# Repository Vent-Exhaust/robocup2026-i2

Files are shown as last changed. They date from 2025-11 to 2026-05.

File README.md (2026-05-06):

# robocup2026
# Vent Exhaust - RoboCup Singapore Soccer Infrared Junior 

<!-- <img src="https://github.com/2-chairs/robocup2025/blob/main/zLogo/v3/logo%20render%20v3.png" alt="" width="100"/> -->

*Repository for the official electronic, mechanical, and software files of Vent Exhaust (VE) 1, formerly known as 2 Chairs.*

<p align="center">
  <a href="media/photos/_DSC8658.jpg">
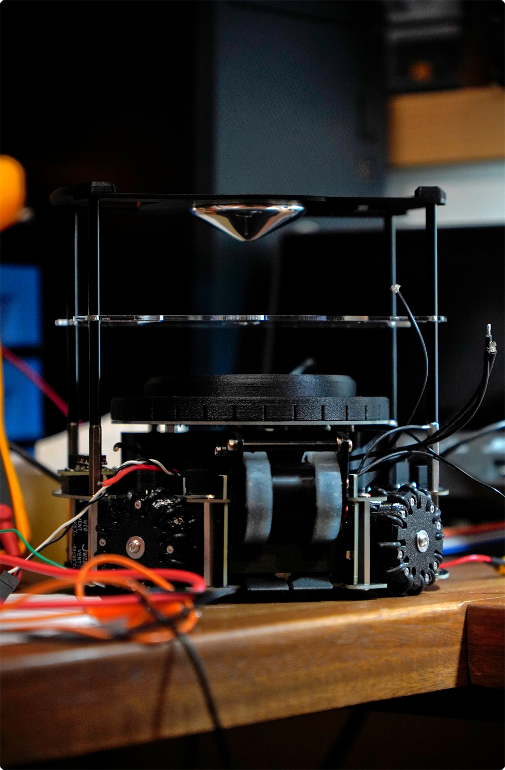
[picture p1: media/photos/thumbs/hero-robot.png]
Vent Exhaust robot
    
  </a>
</p>

## About

This repository is for **Vent Exhaust**, a Singapore RoboCup Infrared Soccer Junior team, and includes relevant design files and resources.

## Repository Structure

- **elec/** - PCB designs, schematics, and component footprints.
- **mech/** - 3D-printable files in **.3MF** and **.STL** formats; includes rendered images of the robot and its mirrored counterpart for reference and other files related to mechanical design.
- **code/** - PlatformIO firmware for the 3-layer robot architecture (Layer 1-3 Teensies / ESP32).
- **cam/** - MicroPython camera firmware (`cam.py`) running on an OpenMV H7 Plus, detecting goals and ball over serial.
- **branding/** - Official team branding and design assets.
- **media/** - Robot photos, gallery thumbnails, screenshots, and reference images used by the README and project documentation.

## Mechanical CAD

- [View the Fusion 360 model](https://a360.co/4tRNy74)

## Robot Gallery

<p align="center">
  <a href="media/photos/bot-with-trophy.jpeg">
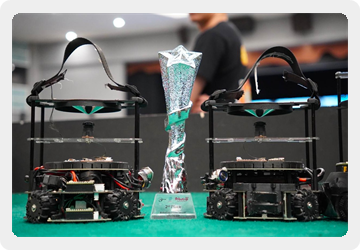
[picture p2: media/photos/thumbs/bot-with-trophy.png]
Robot with trophy
    
  </a>
  <a href="media/photos/_DSC9165.jpg">
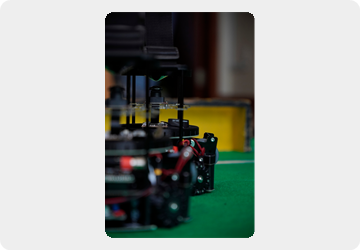
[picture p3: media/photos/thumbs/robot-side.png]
Robot side view
    
  </a>
  <a href="media/photos/_DSC9409.jpg">
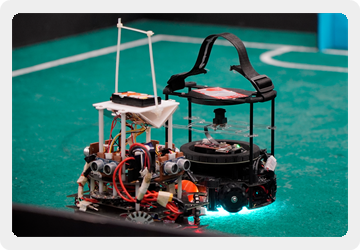
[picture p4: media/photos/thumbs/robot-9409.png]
Robot gallery photo
    
  </a>
  <a href="media/photos/_DSC9172.jpg">
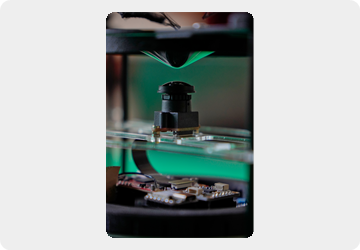
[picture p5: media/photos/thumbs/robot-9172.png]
Robot gallery photo
    
  </a>
  <br>
  <a href="media/photos/_DSC9811.jpg">
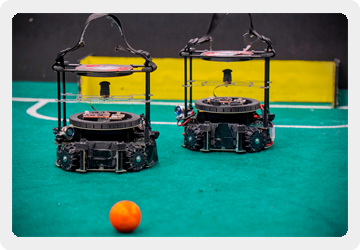
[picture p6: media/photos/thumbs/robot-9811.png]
Robot gallery photo
    
  </a>
  <a href="media/photos/_DSC9160.jpg">
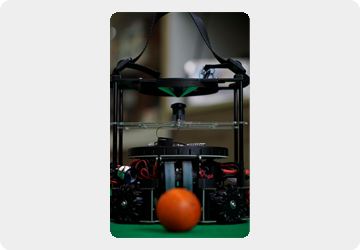
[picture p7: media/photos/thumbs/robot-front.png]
Robot front view
    
  </a>
  <a href="media/photos/_DSC9834.jpg">
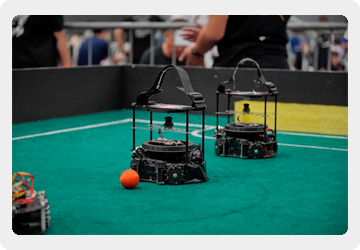
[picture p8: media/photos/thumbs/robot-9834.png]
Robot gallery photo
    
  </a>
</p>

## Robot Architecture

Three processors communicate over UART using a custom SerialComm packet protocol:

| Layer | Hardware | Role |
|---|---|---|
| Layer 1 | Teensy 4.0 | 32-LDR light ring - white line detection |
| Layer 2 | Teensy 4.0 | Main brain - strategy, X-drive motors, IMU heading hold, localisation, scoring |
| Layer 3 | Seeed XIAO ESP32-C3 | 28-IR sensor ring - ball detection + 4 DIP switches |
| Camera | OpenMV H7 Plus (MicroPython) | Dual-goal + ball vision -> serial CSV to Layer 2 |

## Branch Archive

`main` is the active branch. Previous development branches are preserved as
Git tags under `archive/`, such as `archive/i4-v3` and `archive/striker`.

## License & Copyright

Copyright 2026 Vent Exhaust. All rights reserved, except where otherwise stated.

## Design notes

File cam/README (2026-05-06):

cam/
└── cam.py   — MicroPython camera firmware (runs on OpenMV H7 Plus)
                Detects blue goal, yellow goal, and orange ball via colour blobs.
                Outputs a CSV line over UART every frame:

                  BX,<x>,<y>,<dist>,<angle>,<lb_dist>,<lb_angle>,
                  BY,<x>,<y>,<dist>,<angle>,<lb_dist>,<lb_angle>,
                  BALL,<x>,<y>,<dist>,<angle>

                Layer 2 reads this on Serial3 via cam_comm.

Key tuning constants (top of cam.py):
  window_x / window_y     — capture resolution (default 480×480)
  OPTICAL_OFFSET_X/Y      — lens centre correction
  BALL_ROI_SIZE           — square ROI for ball detection
  DEBUG_* flags           — enable/disable drawing overlays and serial debug prints

Coordinate convention:
  x/y — pixel coordinates, origin top-left
  dist — approximate distance derived from blob area (arbitrary units)
  angle — angle to blob centre relative to image centre, degrees
  lb_* — largest-blob variant used for scoring aim

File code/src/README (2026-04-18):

src/
├── layer1/   — Teensy 4.0 — light ring sensing + line detection
│               Reads 32 LDR sensors via MUX, runs findLine(), transmits
│               results (lineDetected, angle, size) to layer2 over Serial1→Serial4.
│               Libraries: light_ring, angle_utils, serial_comm
│
├── layer2/   — Teensy 4.0 — strategy + locomotion
│               Main brain: state machine (ORBIT, IR CHASE, SCORING, RTC, IDLE,
│               LINE DETECTED), X-drive motor control, BNO085 IMU heading-hold PID,
│               camera-based localisation (dual-goal triangulation), dribbler/kicker.
│               Receives: L1 via Serial4, L3 via Serial5, camera via Serial3.
│               Libraries: movement, scoring, cam_comm, layer1_comm, layer3_comm,
│                          serial_comm, angle_utils
│
└── layer3/   — Seeed XIAO ESP32-C3 — IR ball detection + DIP switches
                Polls 28-IR sensor ring, clusters readings to find ball angle,
                reads 4 DIP switches (goal colour, role, strat0, strat1).
                Sends ball angle + switch states to layer2 over Serial1→Serial5.
                Libraries: serial_comm

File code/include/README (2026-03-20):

include/
└── config.h   — project-wide tuning constants, shared across all environments

config.h is the first file to edit on competition day. Sections:

  Light Ring
    LDR_THRESHOLDS[32]        per-sensor white/green thresholds (run calibration to generate)
    LDR_SAMPLES               ADC samples averaged per sensor read
    MUX_SETTLE_US             µs to wait after mux channel switch before reading
    CALIBRATION_READS_PER_SAMPLE

  Main Loop
    LOOP_DELAY_MS             layer1 polling period

  Layer 2 — Motor Trim
    FR_TRIM, BR_TRIM,         per-motor speed multipliers (0.0–1.0)
    BL_TRIM, FL_TRIM          slowest motor stays at 1.0; reduce faster motors

  Layer 2 — IMU Correction
    YAW_KP/KI/KD/I_MAX       heading-hold PID gains
    YAW_CORRECTION_MAX        max omega correction added by yaw PID (0–1 scale)
    ACCEL_KP                  drift correction proportional gain
    ACCEL_CORRECTION_MAX      max vx/vy correction from accel

No other files need to be touched for day-of tuning.

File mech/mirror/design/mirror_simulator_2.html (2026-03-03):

# 🔬 Catadioptric Mirror Simulator

Design and simulate mirrors for OpenMV H7 Plus camera (OV5640 sensor, 2.8mm lens)

### Camera Parameters

Sensor Height (cm): 9.51

Focal Length (mm): 2.8

### Mirror Parameters

Mirror Top Height (cm): 17.03

Viewing Range (cm): 150

Cone Radius Param (cm): 4.7 Controls mirror width

Resolution: 200

🔄 Regenerate Mirror 💾 Download Profile Data 📦 Export for Fusion 360

### 📊 Mirror Stats

Generating...

### ℹ️ Instructions

1. Adjust parameters above
2. Watch the mirror shape update
3. Download profile for Fusion 360
4. Pink rays: ground to mirror
5. Green rays: mirror to lens

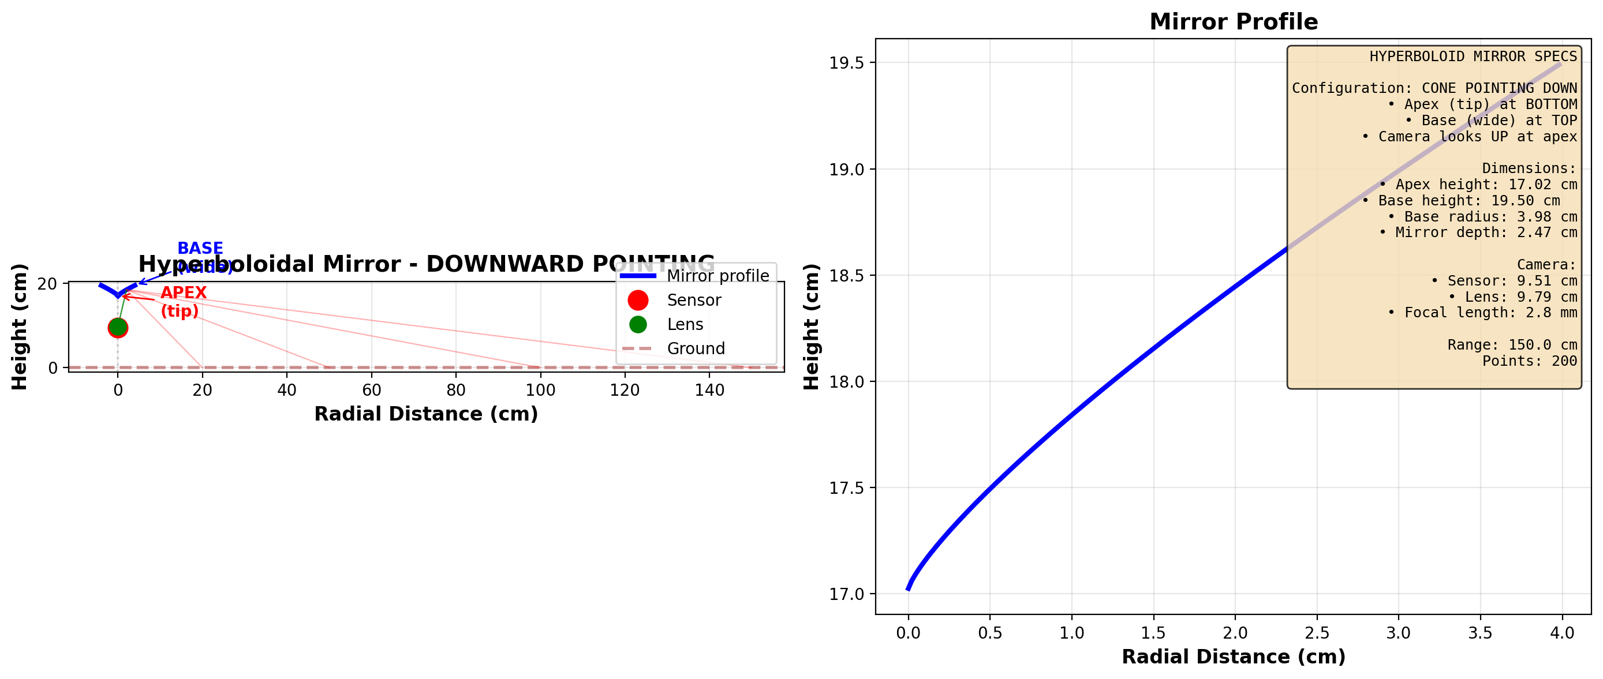
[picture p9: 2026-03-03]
mech/mirror/design/hyperboloid_mirror.png

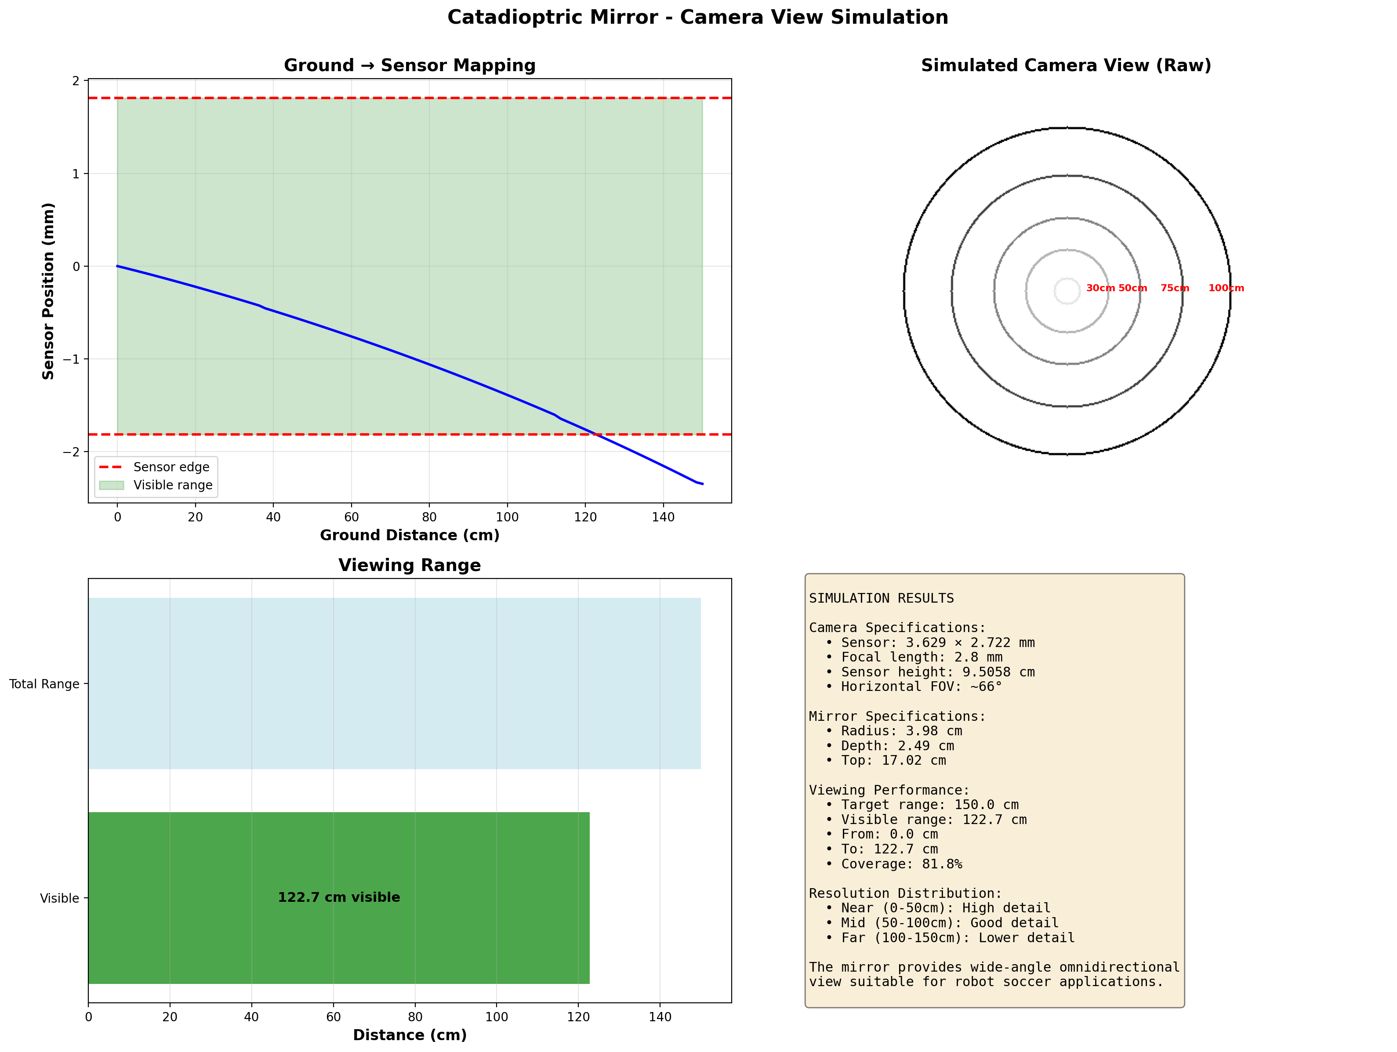
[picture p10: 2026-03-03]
mech/mirror/design/camera_view_simulation.png

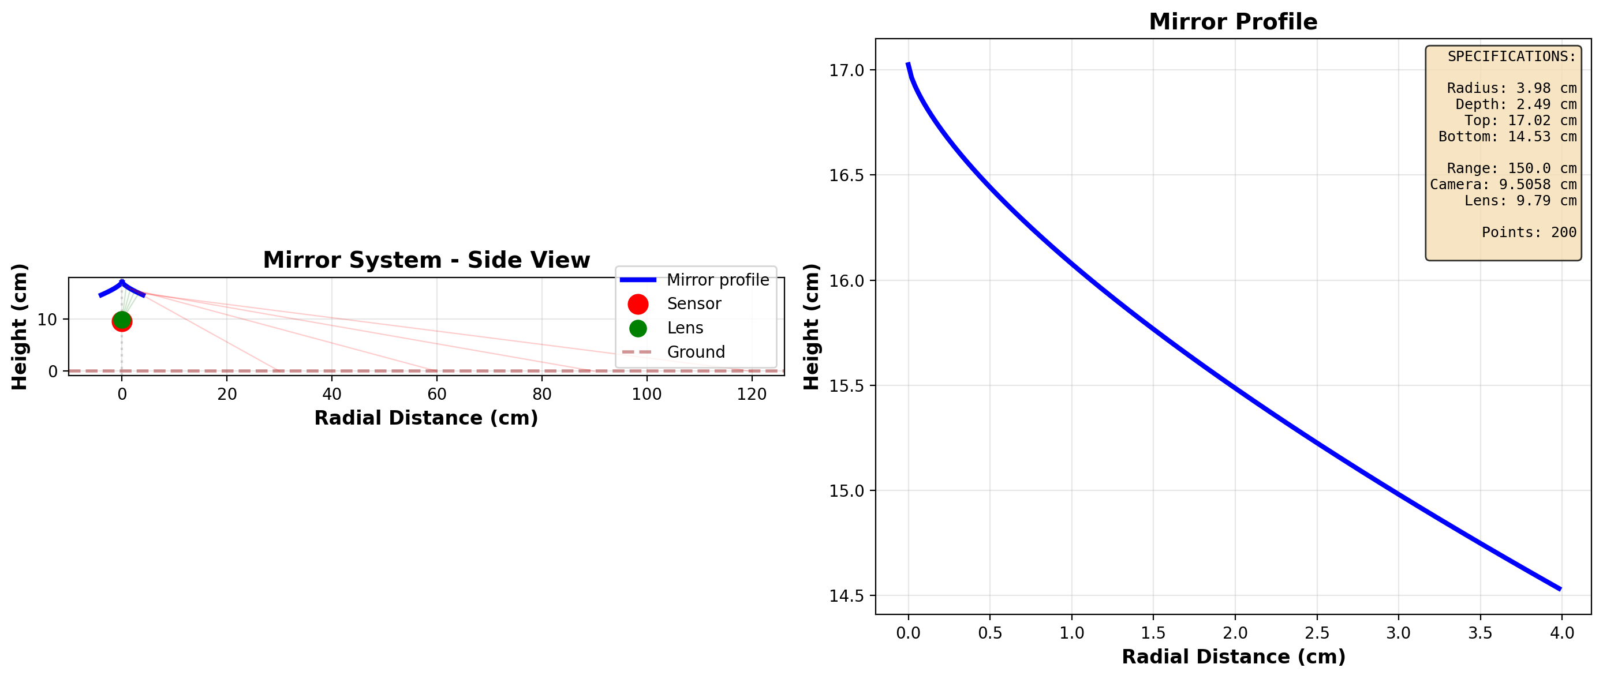
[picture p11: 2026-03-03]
mech/mirror/design/mirror_final.png

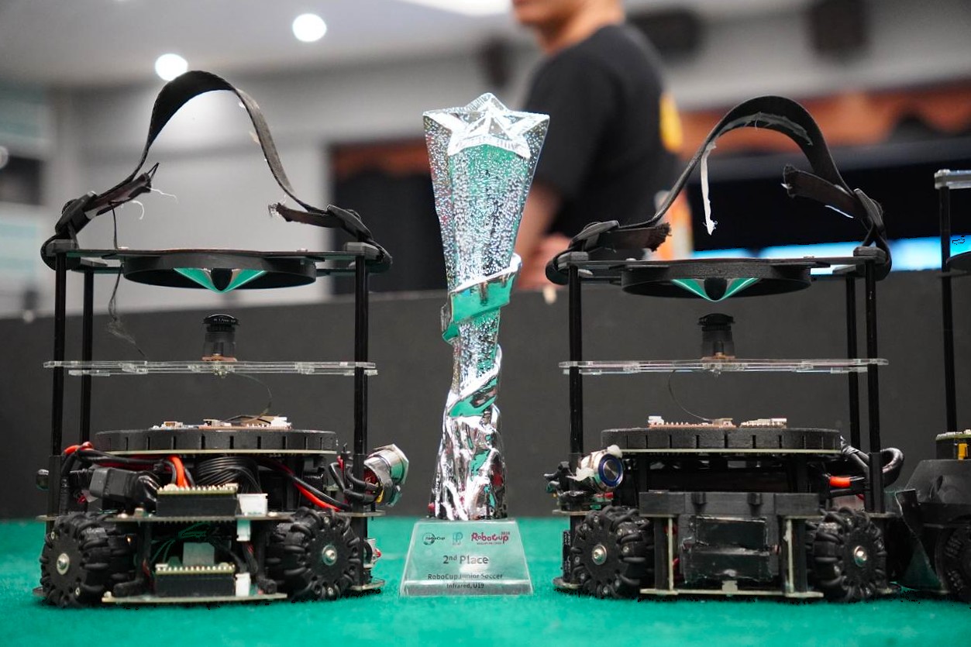
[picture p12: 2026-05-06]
media/photos/bot-with-trophy.jpeg

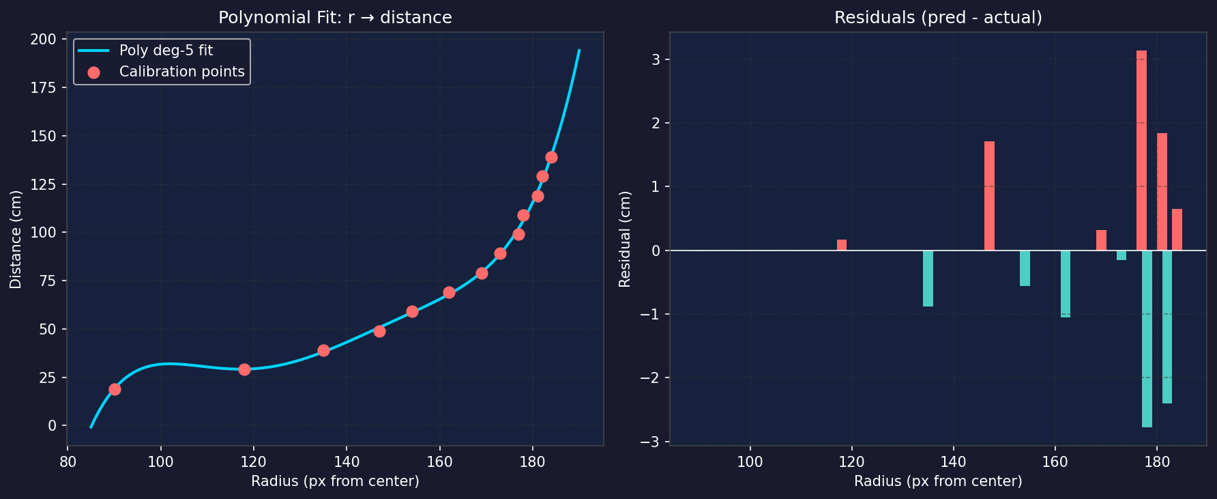
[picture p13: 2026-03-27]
media/poly_fit.png

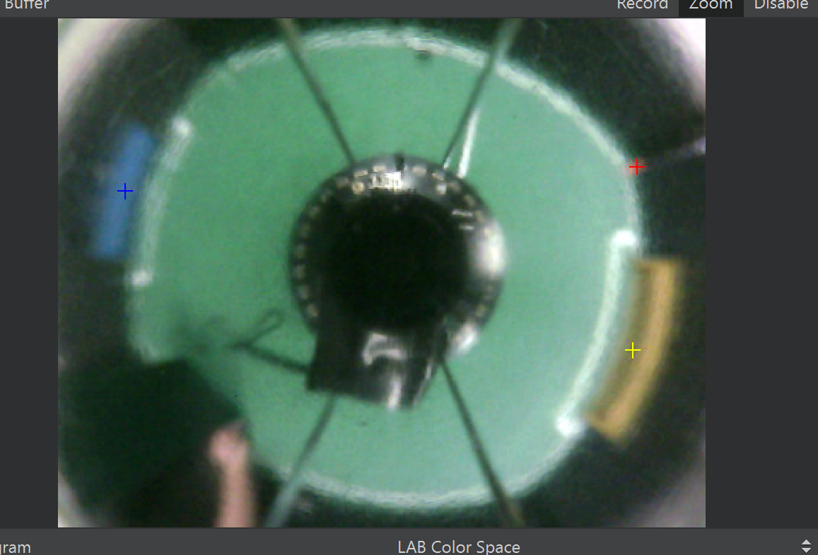
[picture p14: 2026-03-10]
media/media1.png

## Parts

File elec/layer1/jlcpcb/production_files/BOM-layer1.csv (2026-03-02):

Comment | Designator | Footprint | LCSC | Quantity
0R39 | R37,R38,R39,R40,R41,R42,R43,R44,R45,R46,R47,R48,R49,R50,R51,R52,R53,R54,R55,R56,R57,R58,R59,R60,R61,R62,R63,R64,R65,R66,R67 | R_0603_1608Metric | C22859 | 31
100nF | C1,C2 | C_0603_1608Metric | C14663 | 2
10R | R5 | R_0603_1608Metric | C22859 | 1
10k | R1,R4 | C_0603_1608Metric | C25804 | 2
220u | C5,C6 | CP_EIA-7343-15_Kemet-W_HandSolder | C7231 | 2
3k | R2,R3 | C_0603_1608Metric | C4211 | 2
CD74HC4067SM | U1,U2 | CD74HC4067SM | C98457 | 2
D_Photo | D33,D65,D66,D67,D68,D69,D70,D71,D72,D73,D74,D75,D76,D77,D78,D79,D80,D81,D82,D83,D84,D85,D86,D87,D88,D89,D90,D91,D92,D93,D94,D95 | D_0603_1608Metric | C146233 | 32
LED | D1,D100,D101,D102,D103,D104,D105,D106,D107,D108,D109,D110,D111,D112,D113,D114,D115,D116,D117,D118,D119,D120,D121,D122,D123,D124,D125,D126,D96,D97,D98,D99 | LED_PLCC_2835 | C385305 | 32

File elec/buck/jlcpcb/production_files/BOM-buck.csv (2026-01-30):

Comment | Designator | Footprint | LCSC | Quantity
1.33k | R1 | R_0603_1608Metric | C22838 | 1
10u | C1,C4 | C_0603_1608Metric | C1691 | 2
2.18k | R2 | R_0603_1608Metric | C862654 | 1
220u | C5,C6 | CP_EIA-7343-15_Kemet-W_HandSolder | C8024 | 2
22u | C2,C3 | C_0603_1608Metric | C59461 | 2
SS54 | D1,D2 | SS54 | C22452 | 2

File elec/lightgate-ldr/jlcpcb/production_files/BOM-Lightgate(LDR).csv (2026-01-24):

Comment | Designator | Footprint | LCSC | Quantity
R_Photo | LED_2 | R_0603_1608Metric |  | 1
Conn_01x02 | J1 | JST_SH_BM02B-SRSS-TB_1x02-1MP_P1.00mm_Vertical |  | 1

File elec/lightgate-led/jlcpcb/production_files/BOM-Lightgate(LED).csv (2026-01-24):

Comment | Designator | Footprint | LCSC | Quantity
Conn_01x02 | J1 | JST_SH_BM02B-SRSS-TB_1x02-1MP_P1.00mm_Vertical |  | 1
WHITE 3528 | LED7 | LED_PLCC_2835 |  | 1

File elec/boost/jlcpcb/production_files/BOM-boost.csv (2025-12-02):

Comment | Designator | Footprint | LCSC | Quantity
0.1uF | C35 | C_0603_1608Metric | C14663 | 1
0.68uF | C40 | C_0603_1608Metric | C24797 | 1
2K/2.94k | R36 | C_0603_1608Metric | C22843 | 1
33uH | L33 | L_APV_APH1040 | C2875750 | 1
3K | R38 | C_0603_1608Metric | C4211 | 1
LM2587S-ADJ | U1 | VREG_TPS79625KTTR | C1355343 | 1
TC33X-2-104E | VR1 | TC33X2104E | C719186 | 1

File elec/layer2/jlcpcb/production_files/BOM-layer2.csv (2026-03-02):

Comment | Designator | Footprint | LCSC | Quantity
10K | R11,R19,R27,R3,R33 | R_0603_1608Metric | C25804 | 5
1K | R12,R13,R14,R15,R16,R20,R21,R22,R23,R24,R28,R29,R30,R31,R32,R4,R5,R6,R7,R8 | R_0603_1608Metric | C21190 | 20
1k | R34 | R_0603_1608Metric | C21190 | 1
3K3 | R1,R10,R17,R18,R2,R25,R26,R9 | R_0603_1608Metric | C22978 | 8
AON6354 | Q1,Q2,Q3,Q4 | 8-DFN (5x6) | C404363 | 4
VNH5019ATR-E | U2,U4,U6,U8 | VNH5019ATR-E | C2653552 | 4

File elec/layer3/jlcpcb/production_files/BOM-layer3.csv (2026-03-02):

Comment | Designator | Footprint | LCSC | Quantity
.1uF | C1,C34 | C_0603_1608Metric | C1591 | 2
10k | R2,R43 | R_0603_1608Metric | C25804 | 2
CD74HC4067SM | U1,U2 | CD74HC4067SM | C98457 | 2
R | R3,R4 | R_0603_1608Metric_Pad0.98x0.95mm_HandSolder | C25804 | 2
113991054 | U5 | XiaoSeeedStudioEsp32 |  | 1
~ | U6 | OPENMV_M7 |  | 1
XT30PW-M | J8 | AMASS_XT30UPB-M_1x02_P5.0mm_Vertical |  | 1
4754 | U4 | MODULE_4754 |  | 1
XT30PW-M | J9 | AMASS_XT30UPB-M_1x02_P5.0mm_Vertical |  | 1
TSSP58038 | IR1 | Vishay_MINICAST-3Pin |  | 1
Conn_01x05 | J10 | JST_XH_B5B-XH-A_1x05_P2.50mm_Vertical |  | 1
Conn_01x05 | J4 | JST_XH_B5B-XH-A_1x05_P2.50mm_Vertical |  | 1
SW_SPDT_312 | SW2 | SS12D00G3 |  | 1
SW_SPDT_312 | SW4 | SS12D00G3 |  | 1
SW_SPDT_312 | SW1 | SS12D00G3 |  | 1
SW_SPDT_312 | SW3 | SS12D00G3 |  | 1
TSSP58038 | IR11 | Vishay_MINICAST-3Pin |  | 1
TSSP58038 | IR23 | Vishay_MINICAST-3Pin |  | 1
TSSP58038 | IR28 | Vishay_MINICAST-3Pin |  | 1
TSSP58038 | IR8 | Vishay_MINICAST-3Pin |  | 1
TSSP58038 | IR19 | Vishay_MINICAST-3Pin |  | 1
TSSP58038 | IR24 | Vishay_MINICAST-3Pin |  | 1
TSSP58038 | IR3 | Vishay_MINICAST-3Pin |  | 1
TSSP58038 | IR15 | Vishay_MINICAST-3Pin |  | 1
TSSP58038 | IR16 | Vishay_MINICAST-3Pin |  | 1
TSSP58038 | IR14 | Vishay_MINICAST-3Pin |  | 1
TSSP58038 | IR9 | Vishay_MINICAST-3Pin |  | 1
TSSP58038 | IR5 | Vishay_MINICAST-3Pin |  | 1
TSSP58038 | IR27 | Vishay_MINICAST-3Pin |  | 1
TSSP58038 | IR25 | Vishay_MINICAST-3Pin |  | 1
TSSP58038 | IR10 | Vishay_MINICAST-3Pin |  | 1
TSSP58038 | IR12 | Vishay_MINICAST-3Pin |  | 1
TSSP58038 | IR17 | Vishay_MINICAST-3Pin |  | 1
TSSP58038 | IR22 | Vishay_MINICAST-3Pin |  | 1
TSSP58038 | IR20 | Vishay_MINICAST-3Pin |  | 1
TSSP58038 | IR4 | Vishay_MINICAST-3Pin |  | 1
TSSP58038 | IR7 | Vishay_MINICAST-3Pin |  | 1
TSSP58038 | IR2 | Vishay_MINICAST-3Pin |  | 1
TSSP58038 | IR18 | Vishay_MINICAST-3Pin |  | 1
TSSP58038 | IR6 | Vishay_MINICAST-3Pin |  | 1
TSSP58038 | IR26 | Vishay_MINICAST-3Pin |  | 1
TSSP58038 | IR13 | Vishay_MINICAST-3Pin |  | 1
TSSP58038 | IR21 | Vishay_MINICAST-3Pin |  | 1

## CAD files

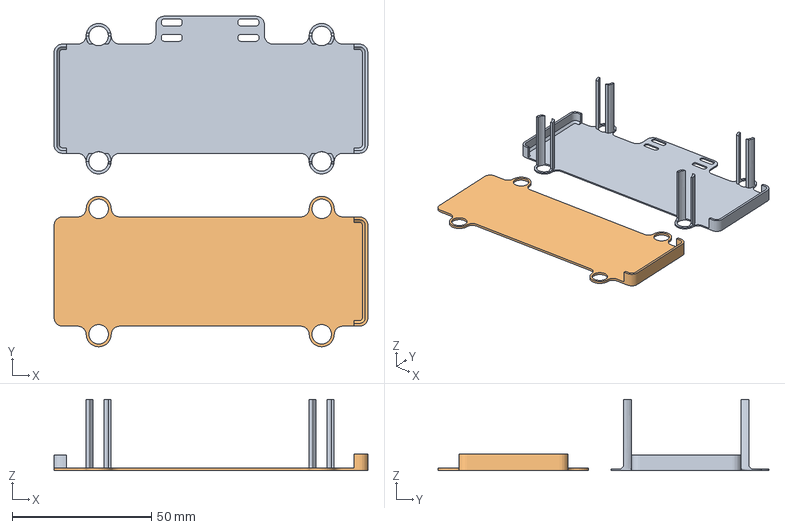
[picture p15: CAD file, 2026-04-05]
mech/3d-printing/battery-mount/battery-mount-assembly.3mf
112.6 x 118.6 x 25.6 mm

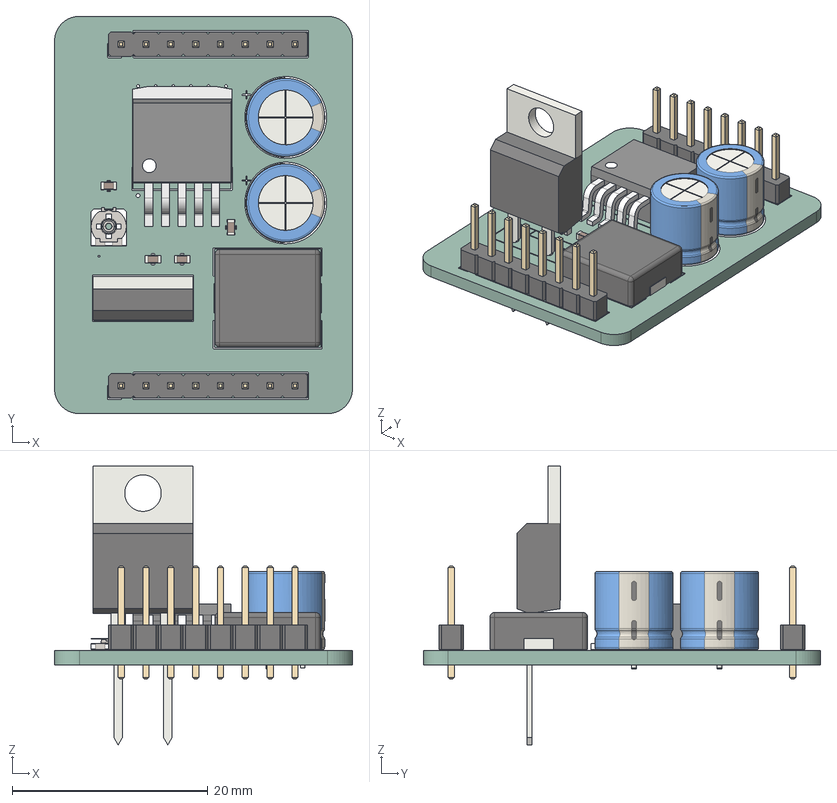
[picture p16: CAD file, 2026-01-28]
elec/boost/boost.step
30.5 x 40.6 x 28.5 mm
C_0603_1608Metric x 4
PinHeader_1x08_P2.54mm_Vertical x 2
LM2587S-ADJ
TC33X-2-104E
CP_Radial_D8.0mm_P3.50mm x 2
TO-220-2_Vertical
L_APV_APH1040
boost_silkscreen x 2
boost_PCB

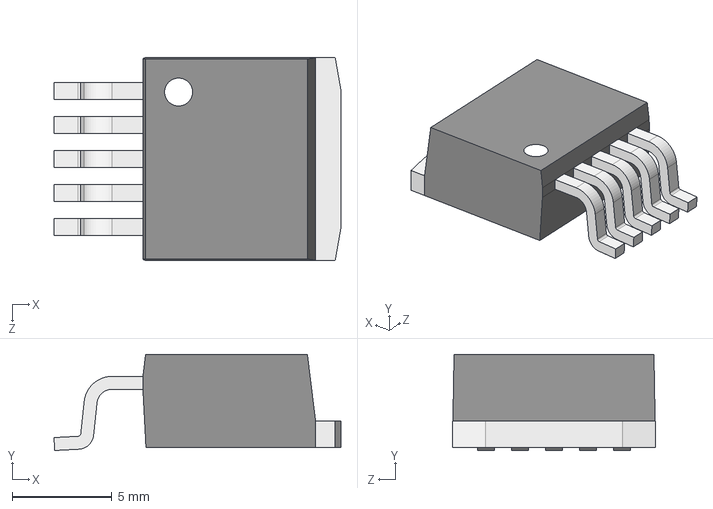
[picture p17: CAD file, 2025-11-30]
elec/boost/LIB_LM2587S-ADJ/LM2587S-ADJ/3D/LM2587S-ADJ.stp
14.4 x 4.80 x 10.2 mm

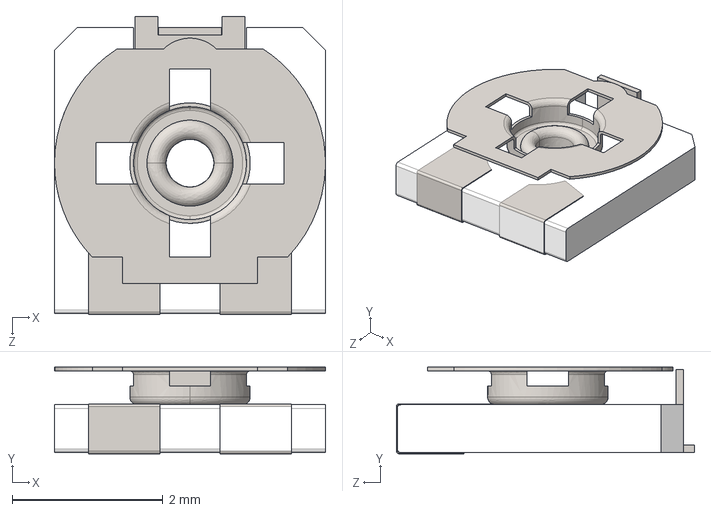
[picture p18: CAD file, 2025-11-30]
elec/boost/LIB_TC33X-2-104E/LIB_TC33X-2-104E/TC33X-2-104E/3D/TC33X-2-104E.stp
3.60 x 1.15 x 3.96 mm

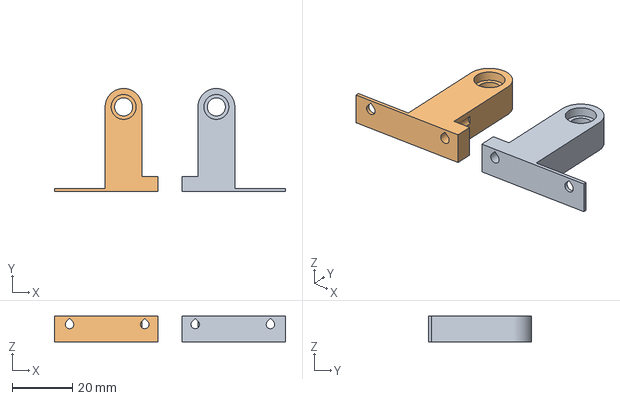
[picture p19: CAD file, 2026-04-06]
mech/3d-printing/dribbler/dribbler-mount.3mf
76.9 x 34.3 x 8.50 mm
dribbler-mount-left
dribbler-mount-right

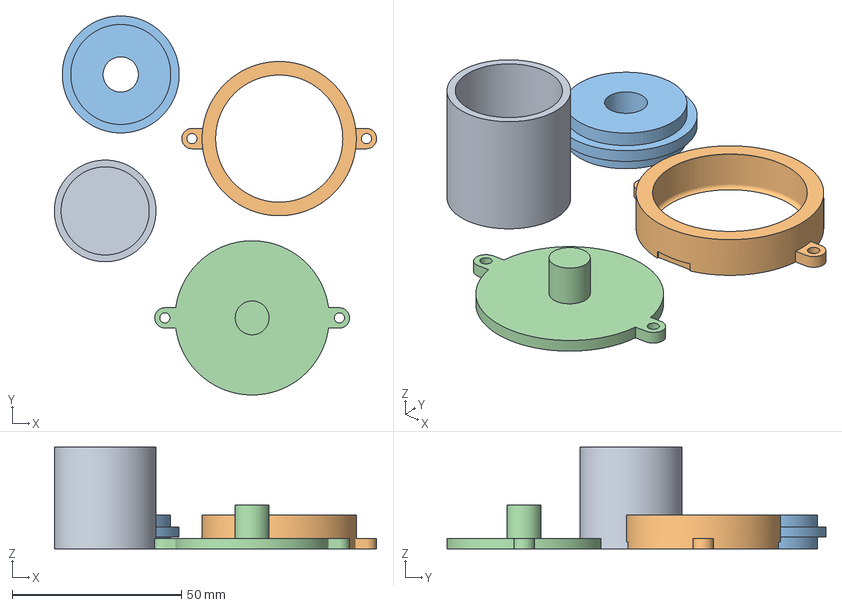
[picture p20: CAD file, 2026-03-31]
mech/3d-printing/dribbler/mould/cup-and-mould.3mf
95.1 x 111.8 x 30.0 mm
cup

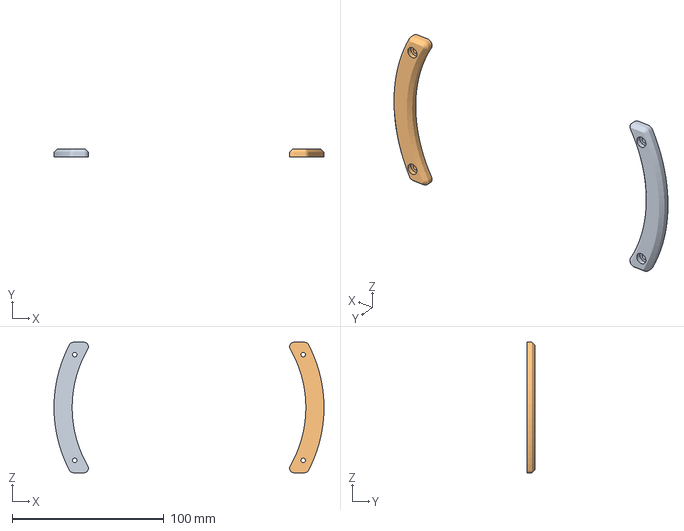
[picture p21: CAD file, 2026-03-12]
mech/3d-printing/handle/handle-mount.3mf
177.9 x 5.00 x 86.1 mm

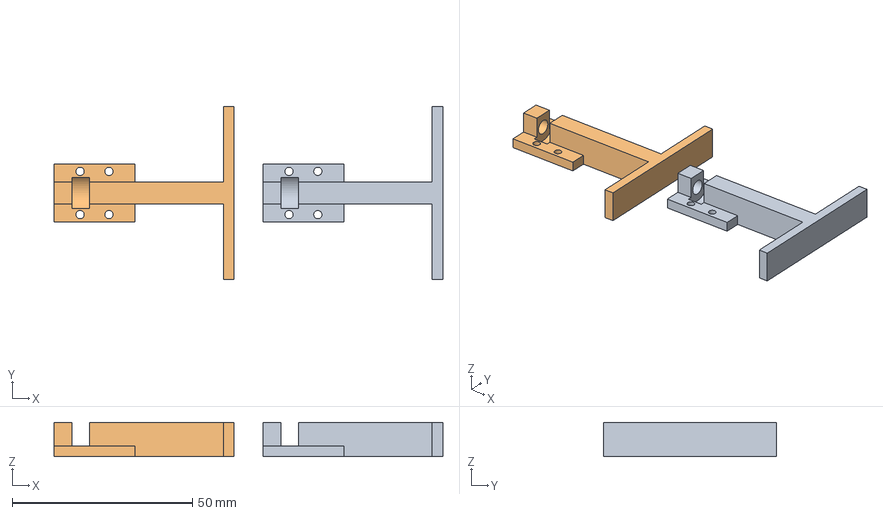
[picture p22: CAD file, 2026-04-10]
mech/3d-printing/kicker/kicker-plate-v2.3mf
108.0 x 48.0 x 9.50 mm
kicker-plate-v2 x 2

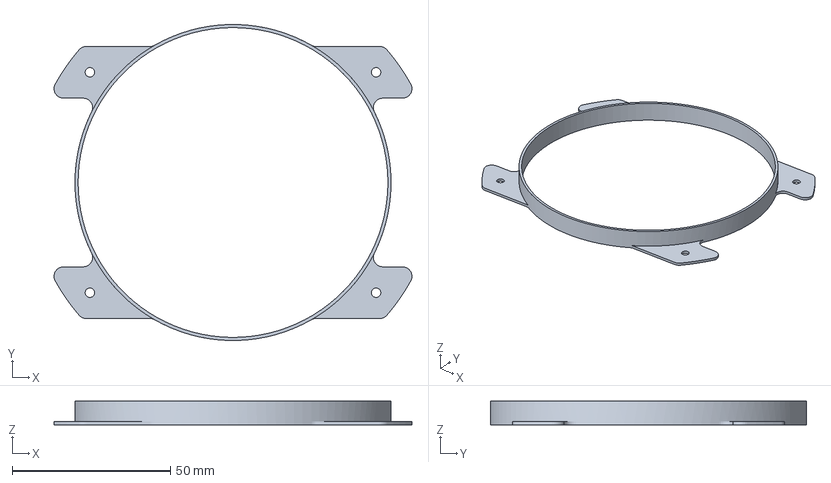
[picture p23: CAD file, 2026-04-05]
mech/3d-printing/shell/layer4-shell.3mf
113.3 x 100.0 x 7.50 mm

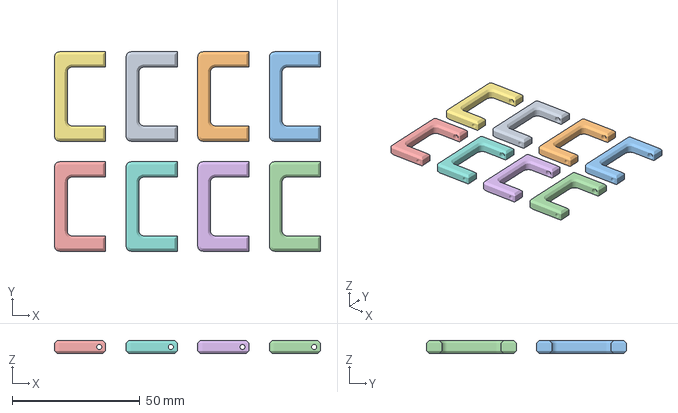
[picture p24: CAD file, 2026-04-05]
mech/3d-printing/standoffs/m2-m3-standoff.3mf
104.0 x 78.0 x 5.00 mm
m2-m3-standoff x 8

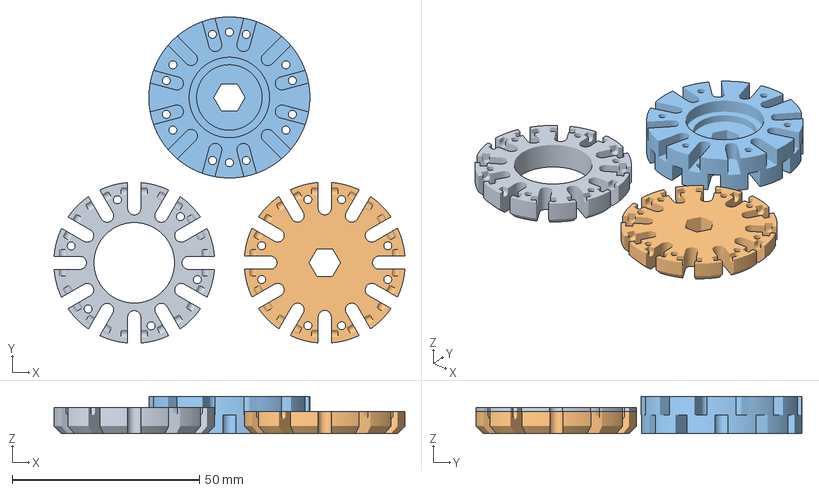
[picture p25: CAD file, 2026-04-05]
mech/3d-printing/wheels/wheels-all-layers.3mf
93.7 x 87.1 x 10.0 mm
inner-layer
outer-layer
middle-layer

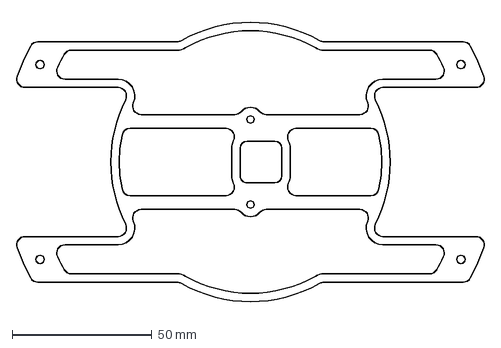
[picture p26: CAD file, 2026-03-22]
mech/laser-cutting/src-2026-03-22/camera-mount.dxf
167.7 x 104.4 mm

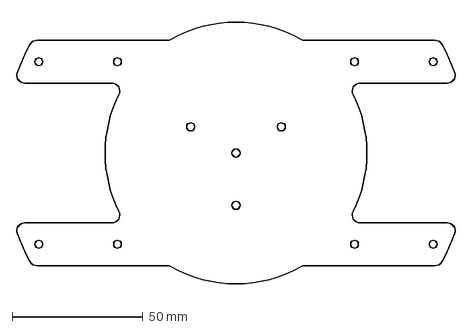
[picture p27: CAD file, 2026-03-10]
mech/laser-cutting/src-2026-04-05/layer4-pcb.dxf
167.7 x 104.4 mm

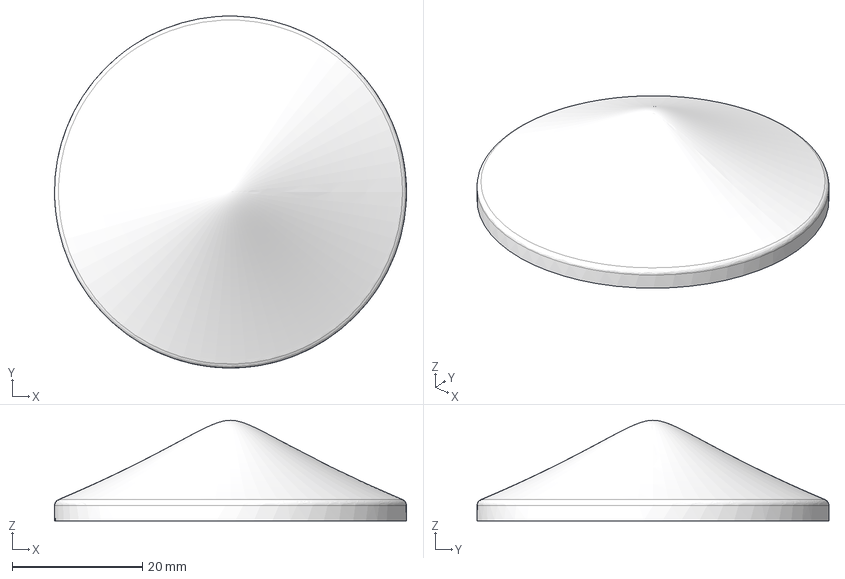
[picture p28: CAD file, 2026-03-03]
mech/mirror/i6/Cone i6.step
54.1 x 54.1 x 15.4 mm

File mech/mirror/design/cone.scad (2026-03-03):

points=[
[0.000000,10.400000],
[0.000000,10.400000],
[0.021811,10.400131],
[0.043623,10.400104],
[0.065434,10.399920],
[0.087243,10.399579],
[0.109049,10.399081],
[0.130851,10.398427],
[0.152648,10.397619],
[0.174438,10.396657],
[0.196222,10.395542],
[0.217997,10.394277],
[0.239763,10.392862],
[0.261518,10.391300],
[0.283263,10.389592],
[0.304996,10.387740],
[0.326717,10.385747],
[0.348424,10.383615],
[0.370117,10.381345],
[0.391796,10.378941],
[0.413460,10.376405],
[0.435108,10.373740],
[0.456740,10.370947],
[0.478356,10.368031],
[0.499956,10.364993],
[0.521538,10.361837],
[0.543103,10.358565],
[0.564650,10.355181],
[0.586180,10.351687],
[0.607693,10.348085],
[0.629188,10.344380],
[0.650665,10.340574],
[0.672124,10.336670],
[0.693566,10.332670],
[0.714991,10.328578],
[0.736398,10.324397],
[0.757788,10.320129],
[0.779161,10.315778],
[0.800518,10.311345],
[0.821858,10.306835],
[0.843182,10.302249],
[0.864491,10.297590],
[0.885784,10.292861],
[0.907061,10.288064],
[0.928324,10.283202],
[0.949573,10.278278],
[0.970808,10.273294],
[0.992029,10.268252],
[1.013236,10.263155],
[1.034431,10.258005],
[1.055614,10.252803],
[1.076785,10.247554],
[1.097944,10.242257],
[1.119091,10.236917],
[1.140228,10.231533],
[1.161355,10.226110],
[1.182472,10.220648],
[1.203579,10.215149],
[1.224677,10.209615],
[1.245767,10.204048],
[1.266848,10.198450],
[1.287921,10.192822],
[1.308986,10.187165],
[1.330045,10.181482],
[1.351096,10.175774],
[1.372142,10.170043],
[1.393181,10.164289],
[1.414214,10.158514],
[1.435242,10.152719],
[1.456265,10.146907],
[1.477283,10.141077],
[1.498297,10.135231],
[1.519307,10.129371],
[1.540313,10.123497],
[1.561315,10.117611],
[1.582314,10.111713],
[1.603311,10.105804],
[1.624304,10.099887],
[1.645296,10.093960],
[1.666285,10.088026],
[1.687272,10.082085],
[1.708257,10.076139],
[1.729241,10.070187],
[1.750224,10.064230],
[1.771206,10.058271],
[1.792186,10.052308],
[1.813167,10.046343],
[1.834147,10.040376],
[1.855126,10.034409],
[1.876106,10.028442],
[1.897085,10.022474],
[1.918065,10.016508],
[1.939046,10.010543],
[1.960026,10.004580],
[1.981008,9.998620],
[2.001990,9.992662],
[2.022974,9.986709],
[2.043958,9.980759],
[2.064944,9.974813],
[2.085931,9.968872],
[2.106920,9.962936],
[2.127910,9.957006],
[2.148902,9.951081],
[2.169895,9.945163],
[2.190890,9.939252],
[2.211888,9.933347],
[2.232887,9.927449],
[2.253888,9.921559],
[2.274892,9.915677],
[2.295898,9.909803],
[2.316906,9.903937],
[2.337917,9.898079],
[2.358930,9.892231],
[2.379945,9.886391],
[2.400963,9.880561],
[2.421984,9.874740],
[2.443007,9.868928],
[2.464033,9.863127],
[2.485062,9.857335],
[2.506094,9.851554],
[2.527128,9.845782],
[2.548165,9.840021],
[2.569205,9.834271],
[2.590248,9.828531],
[2.611294,9.822803],
[2.632343,9.817085],
[2.653395,9.811378],
[2.674450,9.805683],
[2.695508,9.799998],
[2.716569,9.794325],
[2.737634,9.788664],
[2.758701,9.783014],
[2.779771,9.777375],
[2.800845,9.771749],
[2.821921,9.766134],
[2.843001,9.760531],
[2.864084,9.754939],
[2.885170,9.749360],
[2.906260,9.743793],
[2.927352,9.738237],
[2.948448,9.732694],
[2.969546,9.727163],
[2.990648,9.721644],
[3.011753,9.716137],
[3.032862,9.710642],
[3.053973,9.705160],
[3.075088,9.699690],
[3.096206,9.694232],
[3.117327,9.688786],
[3.138451,9.683353],
[3.159578,9.677932],
[3.180709,9.672523],
[3.201842,9.667126],
[3.222979,9.661742],
[3.244119,9.656370],
[3.265262,9.651011],
[3.286408,9.645663],
[3.307557,9.640328],
[3.328710,9.635006],
[3.349865,9.629695],
[3.371024,9.624397],
[3.392185,9.619111],
[3.413350,9.613838],
[3.434518,9.608576],
[3.455688,9.603327],
[3.476862,9.598090],
[3.498039,9.592865],
[3.519218,9.587652],
[3.540401,9.582452],
[3.561587,9.577263],
[3.582775,9.572087],
[3.603967,9.566922],
[3.625161,9.561770],
[3.646359,9.556630],
[3.667559,9.551501],
[3.688762,9.546385],
[3.709968,9.541280],
[3.731177,9.536187],
[3.752389,9.531106],
[3.773603,9.526037],
[3.794821,9.520980],
[3.816041,9.515935],
[3.837264,9.510901],
[3.858490,9.505878],
[3.837261,9.510889],
[3.858500,9.505923],
[3.837258,9.510878],
[3.858510,9.505966],
[3.837256,9.510867],
[3.858520,9.506008],
[3.879786,9.501161],
[3.858517,9.505998],
[3.837239,9.510794],
[3.858527,9.506039],
[3.879816,9.501294],
[3.858524,9.506029],
[3.879825,9.501334],
[3.858522,9.506020],
[3.879834,9.501374],
[3.858520,9.506010],
[3.879842,9.501413],
[3.858518,9.506001],
[3.879850,9.501451],
[3.858516,9.505993],
[3.837175,9.510497],
[3.858524,9.506030],
[3.879875,9.501571],
[3.858523,9.506022],
[3.879883,9.501608],
[3.858521,9.506014],
[3.879890,9.501643],
[3.858519,9.506006],
[3.879898,9.501679],
[3.858518,9.505999],
[3.837131,9.510285],
[3.858525,9.506034],
[3.879920,9.501789],
[3.858523,9.506027],
[3.879926,9.501823],
[3.858522,9.506020],
[3.879933,9.501856],
[3.858521,9.506014],
[3.879939,9.501889],
[3.858520,9.506007],
[3.879945,9.501921],
[3.858519,9.506001],
[3.879951,9.501953],
[3.858517,9.505995],
[3.837078,9.510007],
[3.858523,9.506027],
[3.879970,9.502052],
[3.858522,9.506021],
[3.879975,9.502083],
[3.858521,9.506016],
[3.879981,9.502113],
[3.858520,9.506011],
[3.879986,9.502142],
[3.858519,9.506006],
[3.879992,9.502171],
[3.858519,9.506001],
[3.879997,9.502200],
[3.858518,9.505997],
[3.837034,9.509765],
[3.858523,9.506025],
[3.880012,9.502289],
[3.858522,9.506021],
[3.880017,9.502317],
[3.858521,9.506016],
[3.880022,9.502344],
[3.858521,9.506012],
[3.880026,9.502371],
[3.858520,9.506009],
[3.880031,9.502398],
[3.858519,9.506005],
[3.880035,9.502424],
[3.858519,9.506001],
[3.880039,9.502450],
[3.858518,9.505998],
[3.836993,9.509521],
[3.858522,9.506023],
[3.880052,9.502529],
[3.858522,9.506020],
[3.880056,9.502554],
[3.858521,9.506017],
[3.880060,9.502579],
[3.858521,9.506014],
[3.880064,9.502603],
[3.858520,9.506011],
[3.880068,9.502627],
[3.858520,9.506009],
[3.880072,9.502651],
[3.858520,9.506006],
[3.880075,9.502674],
[3.858519,9.506004],
[3.880079,9.502698],
[3.858519,9.506001],
[3.880082,9.502721],
[3.858519,9.505999],
[3.836951,9.509255],
[3.858522,9.506022],
[3.880093,9.502790],
[3.858522,9.506019],
[3.880096,9.502812],
[3.858521,9.506018],
[3.880100,9.502834],
[3.858521,9.506016],
[3.880103,9.502856],
[3.858521,9.506014],
[3.880106,9.502877],
[3.858521,9.506012],
[3.880109,9.502898],
[3.858520,9.506010],
[3.880112,9.502919],
[3.858520,9.506009],
[3.880115,9.502940],
[3.858520,9.506007],
[3.880118,9.502960],
[3.858520,9.506006],
[3.880121,9.502980],
[3.858519,9.506005],
[3.880123,9.503000],
[3.858519,9.506003],
[3.880126,9.503020],
[3.858519,9.506002],
[3.880129,9.503040],
[3.858519,9.506001],
[3.880131,9.503059],
[3.858519,9.506000],
[3.880134,9.503078],
[3.858519,9.505999],
[3.836901,9.508901],
[3.858521,9.506018],
[3.880142,9.503136],
[3.858521,9.506017],
[3.880144,9.503154],
[3.858521,9.506016],
[3.880147,9.503172],
[3.858521,9.506016],
[3.880149,9.503191],
[3.858521,9.506015],
[3.880151,9.503209],
[3.858521,9.506014],
[3.880154,9.503226],
[3.858521,9.506014],
[3.880156,9.503244],
[3.858521,9.506013],
[3.880158,9.503261],
[3.858521,9.506013],
[3.880160,9.503279],
[3.858521,9.506013],
[3.880162,9.503296],
[3.858520,9.506012],
[3.880165,9.503313],
[3.858520,9.506012],
[3.880167,9.503330],
[3.858520,9.506012],
[3.880169,9.503346],
[3.858520,9.506011],
[3.880171,9.503363],
[3.858520,9.506011],
[3.880173,9.503379],
[3.858520,9.506011],
[3.880175,9.503395],
[3.858520,9.506011],
[3.880177,9.503411],
[3.858520,9.506011],
[3.880178,9.503427],
[3.858520,9.506011],
[3.880180,9.503443],
[3.858520,9.506011],
[3.880182,9.503458],
[3.858520,9.506011],
[3.880184,9.503474],
[3.858520,9.506012],
[3.880186,9.503489],
[3.858520,9.506012],
[3.880188,9.503504],
[3.858520,9.506012],
[3.880189,9.503519],
[3.858520,9.506012],
[3.880191,9.503534],
[3.858521,9.506013],
[3.880193,9.503549],
[3.858521,9.506013],
[3.880194,9.503563],
[3.858521,9.506013],
[3.880196,9.503578],
[3.858521,9.506014],
[3.880198,9.503592],
[3.858521,9.506014],
[3.880199,9.503607],
[3.858521,9.506015],
[3.880201,9.503621],
[3.858521,9.506015],
[3.880202,9.503635],
[3.858521,9.506016],
[3.880204,9.503649],
[3.858521,9.506016],
[3.880205,9.503662],
[3.858521,9.506017],
[3.880207,9.503676],
[3.858521,9.506018],
[3.880208,9.503690],
[3.858521,9.506018],
[3.880210,9.503703],
[3.858521,9.506019],
[3.880211,9.503716],
[3.858521,9.506020],
[3.880212,9.503730],
[3.858521,9.506020],
[3.880214,9.503743],
[3.858521,9.506021],
[3.880215,9.503756],
[3.858522,9.506022],
[3.880217,9.503769],
[3.858522,9.506023],
[3.880218,9.503781],
[3.858522,9.506024],
[3.880219,9.503794],
[3.858522,9.506024],
[3.880220,9.503807],
[3.858522,9.506025],
[3.880222,9.503819],
[3.858522,9.506026],
[3.880223,9.503832],
[3.858522,9.506027],
[3.880224,9.503844],
[3.858522,9.506028],
[3.880225,9.503856],
[3.858522,9.506029],
[3.880227,9.503868],
[3.858522,9.506030],
[3.880228,9.503880],
[3.858522,9.506031],
[3.880229,9.503892],
[3.858523,9.506032],
[3.880230,9.503904],
[3.858523,9.506033],
[3.880231,9.503916],
[3.858523,9.506034],
[3.880233,9.503928],
[3.858523,9.506035],
[3.880234,9.503939],
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

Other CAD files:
mech/mirror/v3/cone.step
mech/pcbs/layer3.step
mech/3d-printing/dribbler/dribbler-mount-left.3mf
mech/3d-printing/dribbler/mould/cup.3mf
elec/boost/LIB_TC33X-2-104E/LIB_TC33X-2-104E/TC33X-2-104E/Allegro/tc33x2104e.psm
elec/boost/LIB_TC33X-2-104E/LIB_TC33X-2-104E/TC33X-2-104E/DEHDL/tc33x_2_104e/chips/chips.prt
mech/3d-printing/dribbler/42mm-standoff.3mf
mech/3d-printing/dribbler/dribbler-drum-rollers-attachment-i2.3mf
mech/3d-printing/dribbler/dribbler-drum-rollers-attachment.3mf
mech/3d-printing/dribbler/dribbler-mount-right.3mf
mech/3d-printing/dribbler/dribbler-ramp.3mf
mech/3d-printing/dribbler/dribbler-spring-holder.3mf
mech/3d-printing/dribbler/mould/dribbler-mould.3mf
mech/3d-printing/kicker/kicker-plate.3mf
mech/3d-printing/kicker/relay-mount.3mf
mech/3d-printing/shell/IR_Shell (PLA).3mf
mech/3d-printing/shell/IR_Shell.3mf
mech/3d-printing/shell/camera-shroud.3mf
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

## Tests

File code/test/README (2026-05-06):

test/
├── layer1-calibrate/        - Layer 1 light ring calibration build
├── layer1-serial-debug/     - Layer 1 serial packet debug build
├── layer2-cam-debug/        - Layer 2 camera serial/debug build
├── layer2-dribbler-debug/   - Layer 2 dribbler ESC debug build
├── layer2-goalie-debug/     - Layer 2 goalie behaviour debug build
├── layer2-imu-debug/        - Layer 2 IMU debug build
├── layer2-ir-debug/         - Layer 2 IR ball data debug build
├── layer2-loc-center/       - Layer 2 localisation/return-to-centre debug build
├── layer2-motor-debug/      - Layer 2 motor direction/speed debug build
├── layer2-scoring-debug/    - Layer 2 kicker, lightgate, and scoring debug build
└── layer2-serial-debug/     - Layer 2 serial links debug build

Debug/test environments for individual subsystems. Each folder maps to a
PlatformIO environment in platformio.ini. Build and upload with:

    pio run -e layer1-serial-debug --target upload

For future PlatformIO native unit tests, add them here as well:

    [env:native]
    platform = native

    test/test_angle_utils/test_angle_utils.cpp

Run tests with: pio test -e native

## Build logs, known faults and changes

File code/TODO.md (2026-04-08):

# Strategy Implementation TODO

Porting the 2025 strategy into the 2026 i2 codebase. The 2025 code lives in
`ducc/robocup-2025/open/software design/microcontrollers/src/teensy1/`.

Key hardware differences from 2025:
- **We have an IR ring** (28 sensors on L3) — 2025 did not, they relied on camera for ball.
- **Our camera is weak at distance** — use IR as primary ball bearing, camera only when close.
- **No TOFs** — rules prohibit them. Localisation is camera-only (dual-goal triangulation), which we already have.
- **Field units are cm** — 2025 used pixel coordinates (~±800 x-range). Our field is 219x158 cm.

---

## Phase 1: State Machine Foundation

Refactor `src/layer2/main.cpp` from the current flat if-else chain into a task-based state machine.

- [ ] **1.1 Define task enum**
  Add to `src/layer2/main.cpp` (or a new header):
  ```cpp
  enum Task { ORBIT_TO_BALL, SCORE, GOALIE, RETURN_TO_CENTRE, IDLE };
  static Task task = IDLE;
  ```
  **2025 ref**: `teensy1/main.h:694` — `int task;` with values 0/1/2/3
  **Our code**: `src/layer2/main.cpp:111-276` — the current `loop()` if-else chain

- [ ] **1.2 Write `striker()` role function**
  Runs every loop to decide the current task based on catchment state.
  ```
  if kicked recently         -> ORBIT_TO_BALL (reset catchment state)
  if ball in catchment       -> SCORE (record timestamp)
  if was in catchment <500ms -> stay SCORE
  if ball found (IR or cam)  -> ORBIT_TO_BALL
  if locValid                -> RETURN_TO_CENTRE
  else                       -> IDLE
  ```
  **2025 ref**: `teensy1/main.cpp:36-67` — `striker()` function with `catchment_timeout = 500ms`
  **Our code**: `src/layer2/main.cpp:119` — `bool ballCaught = checkCatchment();` currently only used in the if-else

- [ ] **1.3 Write `goalie()` role function**
  Simply sets `task = GOALIE` (goalie logic is in Phase 4).
  **2025 ref**: `teensy1/main.cpp:69-72` — `void goalie()`

- [ ] **1.4 Use DIP switches for role selection**
  L3 already sends 4 DIP switches (`l3SwitchGoal`, `l3SwitchRole`, `l3SwitchStrat0`, `l3SwitchStrat1`).
  Use `l3SwitchRole` to pick striker vs goalie each loop.
  **Our code**: `lib/layer3_comm/layer3_comm.h:17-20` — switch externs

- [ ] **1.5 Refactor `loop()` into `switch(task)`**
  ```cpp
  void loop() {
      // ... read sensors, update localisation (unchanged) ...

      if (l3SwitchRole) striker(); else goalie();

      switch (task) {
      case ORBIT_TO_BALL:  orbitToBall();      break;
      case SCORE:          orbitScore();        break;
      case GOALIE:         defendGoal();        break;
      case RETURN_TO_CENTRE: returnToCentre(); break;
      case IDLE:           stopMotors();        break;
      }

      moveRobot(moveAngle, moveSpeed, omega);
  }
  ```
  Extract each current if-else branch into its own function. No behaviour change yet.
  **2025 ref**: `teensy1/main.cpp:279-332` — the `switch(robot.task)` block

---

## Phase 2: Orbit Refinement

Improve the orbit so the robot approaches the ball from behind (between ball and our goal).

- [ ] **2.1 Determine orbit target bearing**
  The robot should orbit the ball so it ends up between the ball and the opponent's goal.
  - If `camBlueDetected`: target bearing = `camBlueAngle` (goal we're attacking)
  - Else: target bearing = world 0 relative to robot = `-imuYaw` (fallback)
  **2025 ref**: `teensy1/main.cpp:284-291` — uses `blue_open.current_pose.bearing`
  **Our code**: `src/layer2/main.cpp:173-178` — similar logic already exists

- [ ] **2.2 Replace orbit with angular-offset approach**
  2025's orbit adds an angular offset to the ball bearing that shrinks as the robot gets behind the ball.
  Since our camera is bad at distance, simplify:
  - Use IR bearing as the ball direction (reliable at all distances)
  - Compute `alignError` = goal bearing - ball bearing (how far off we are from being behind the ball)
  - Offset = `alignError * scaleFactor` (capped at ±90 degrees)
  - Move direction = IR ball bearing + offset
  - This makes the robot curve around the ball instead of chasing head-on
  **2025 ref**: `teensy1/algorithm.cpp:93-218` — `orbitToBall()`, especially lines 98-108 for the offset calc and 120-128 for the exponential orbit factor
  **Our code**: `src/layer2/main.cpp:164-234` — current orbit uses tangent+creep vector blend

- [ ] **2.3 Speed control without reliable distance**
  Since we can't trust camera ball distance at range:
  - Use `l3BallCount` (number of active IR sensors) as a rough proximity signal — more sensors = closer ball
  - When cam ball is available AND close (< 30cm): use `camBallDist` for fine deceleration
  - Otherwise: use a fixed moderate speed (e.g. 0.15) that slows when IR count is high
  **2025 ref**: `teensy1/algorithm.cpp:130-144` — deceleration curve based on `ball.distance_from_robot`
  **Our code**: `src/layer2/main.cpp:197-198` — `orbitSpeed` is currently based on alignment error only

- [ ] **2.4 Forward creep when aligned**
  When the robot is behind the ball (alignError small), blend in a forward component toward the ball.
  Keep the existing concept but tie it to the new orbit.
  **2025 ref**: implicit — when orbit offset is small, the robot naturally moves toward the ball
  **Our code**: `src/layer2/main.cpp:206-209` — `CREEP_SPEED` logic (keep this)

- [ ] **2.5 Edge speed capping during orbit**
  Already implemented — just make sure it's applied in the orbit function.
  **Our code**: `src/layer2/main.cpp:69-93` — `edgeSpeedCap()`

---

## Phase 3: Scoring Sequence

When the ball is caught, drive toward the goal and kick when aligned.

- [ ] **3.1 Implement `orbitScore()` function**
  Called when `task == SCORE`:
  1. Drive forward (angle = 0 in robot frame) at scoring speed
  2. Set yaw target to face the blue goal: `yawTarget = imuYaw + camBlueAngle`
  3. The existing PID heading hold will rotate the robot to face the goal while moving
  **2025 ref**: `teensy1/algorithm.cpp:263-305` — `orbitScore()` and `scoringStrategyOne()`
  **Our code**: `src/layer2/main.cpp:154-163` — current scoring is just "kick if close to goal"

- [ ] **3.2 Kick condition**
  Kick when:
  - `camBlueDetected` AND `camBlueDist < SCORE_KICK_DIST` (e.g. 50cm)
  - AND `abs(camBlueAngle) < SCORE_ALIGN_THRESH` (e.g. 10 degrees)
  If goal not visible, drive forward for a max time (e.g. 2 seconds) then kick blindly.
  **2025 ref**: `teensy1/algorithm.cpp:335-341` — kicks when `y > 100` and bearing error < 5
  **Our code**: `src/layer2/main.cpp:155` — currently checks `camBlueDist < 50` only

- [ ] **3.3 Add scoring constants to `config.h`**
  ```cpp
  constexpr float SCORE_SPEED         = 0.3f;
  constexpr float SCORE_KICK_DIST     = 50.0f;   // cm
  constexpr float SCORE_ALIGN_THRESH  = 10.0f;   // degrees
  constexpr unsigned long SCORE_TIMEOUT_MS = 2000; // blind kick fallback
  ```
  **Our code**: `include/config.h` — add alongside existing tuning constants

- [ ] **3.4 Line rejection during scoring**
  If line detected while scoring, run the escape logic but keep `task = SCORE` so scoring resumes.
  **2025 ref**: `teensy1/algorithm.cpp:278-282` — `rejectLine(target_bearing)` during score
  **Our code**: `src/layer2/main.cpp:137-153` — current line escape doesn't preserve task state

- [ ] **3.5 Post-kick reset**
  After kicking: stop briefly, reset task to `ORBIT_TO_BALL`, reset catchment state.
  **2025 ref**: `teensy1/main.cpp:38-43` — `if (robot.kicker.kicked) { task = 0; }`
  **Our code**: `lib/scoring/scoring.h:19` — `KICK_COOLDOWN_MS = 1000`

---

## Phase 4: Goalie Mode

Defend goal by tracking the ball along a curved line in front of goal.

- [ ] **4.1 Define the defensive curve**
  2025 used `f(x) = -5e-15 * x^6 - 500` in pixel coords (x range ~±800, y ~ -500 to -700).
  Scale to our cm coords (x range ~±79, field half-Y = 109.5):
  A starting point: `f(x) = -a * x^6 - 30` where the curve sits ~30cm in front of our goal.
  The exact shape needs field tuning — the idea is flat in the middle, curves back at the edges.
  **2025 ref**: `teensy1/robot.cpp:12-14` — `f(x)`, `df(x)`, `d2f(x)`
  Skip Newton's method for now — just clamp target_x to ball's x projected onto the curve.

- [ ] **4.2 Implement `goalieTrack()`**
  1. Use localisation (`locX`, `locY`) for robot position
  2. Estimate ball world position: `ballWorldX = locX + ballRelX` (from IR bearing + rough distance estimate, or just use `locX` offset by IR angle direction)
  3. Find target point on curve: `targetX = clamp(ballWorldX, -60, 60)`, `targetY = f(targetX)`
  4. Move toward that point using `moveToPoint` style logic (angle + speed from distance)
  **2025 ref**: `teensy1/robot.cpp:107-237` — full `goalieTrack()` with Newton's method, PID speed, step-based movement
  **Our code**: `src/layer2/main.cpp:252-270` — `RETURN_TO_CENTRE` logic is similar (move to a world point) — reuse that pattern

- [ ] **4.3 Implement `goalieRush()`**
  When ball is close and in front, charge straight at it:
  - Trigger: IR ball count high (close) AND ball bearing is roughly forward (< 20 degrees off centre)
  - Move direction = ball bearing, speed = high (0.35-0.5)
  **2025 ref**: `teensy1/robot.cpp:239-260` — `goalieRush()`
  **2025 ref**: `teensy1/algorithm.cpp:26-91` — `defendGoal()` with timeout logic (100ms before rushing)

- [ ] **4.4 Implement `defendGoal()` with rush timeout**
  Combines track + rush:
  ```
  if on_line                       -> rejectLine
  if ball in front AND close:
      if close for > 100ms         -> goalieRush()
      else                         -> goalieTrack()
  else                             -> goalieTrack()
  ```
  **2025 ref**: `teensy1/algorithm.cpp:26-91` — full `defendGoal()` state machine

- [ ] **4.5 Add goalie constants to `config.h`**
  ```cpp
  constexpr float GOALIE_CURVE_A       = ???;   // tune on field
  constexpr float GOALIE_CURVE_OFFSET  = -30.0f; // cm in front of goal
  constexpr float GOALIE_X_CLAMP       = 60.0f;  // max x tracking range
  constexpr float GOALIE_RUSH_SPEED    = 0.4f;
  constexpr float GOALIE_TRACK_MIN_SPD = 0.1f;
  constexpr float GOALIE_TRACK_MAX_SPD = 0.35f;
  constexpr unsigned long GOALIE_RUSH_TIMEOUT_MS = 100;
  constexpr float GOALIE_RUSH_ANGLE_THRESH = 20.0f; // degrees
  ```

---

## Phase 5: Polish

- [ ] **5.1 Per-task PID tuning**
  Orbit needs gentle heading hold, scoring needs aggressive snapping.
  Adjust `YAW_KP` dynamically based on current task (or use separate PID instances).
  **2025 ref**: `teensy1/main.cpp:274-276` — `kp` changes per task case
  **Our code**: `include/config.h:58-70` — single `YAW_KP`

- [ ] **5.2 Return-to-centre improvements**
  When ball is lost, go to the side it was last seen instead of dead centre.
  Track `lastBallSide` (positive/negative x when ball was last detected).
  Move to `(sign(lastBallSide) * 30, 0)` instead of `(0, 0)`.
  **2025 ref**: `teensy1/algorithm.cpp:221-258` — uses `ball.ball_last_seen.x` to pick side

- [ ] **5.3 Line rejection preserves task**
  Currently line escape overrides everything. Change so that after escaping, the robot returns to whatever task it was doing (especially important for scoring).
  **2025 ref**: `teensy1/algorithm.cpp:186-196` — `rejectLine(bearing)` during orbit preserves orbit bearing

- [ ] **5.4 Kick cooldown handling**
  After a kick, ignore catchment for `KICK_COOLDOWN_MS` to avoid the lightgate false positive.
  **Our code**: `lib/scoring/scoring.h:19` — `KICK_COOLDOWN_MS = 1000` (already defined, wire it in)

---

## File Reference

| File | Purpose |
|---|---|
| `src/layer2/main.cpp` | Main strategy loop — most changes go here |
| `include/config.h` | Tuning constants — add scoring/goalie params |
| `lib/movement/movement.h` | Motor control, PID, IMU — mostly unchanged |
| `lib/scoring/scoring.h` | Dribbler, kicker, lightgate — mostly unchanged |
| `lib/cam_comm/cam_comm.h` | Camera data — unchanged |
| `lib/layer1_comm/layer1_comm.h` | Line data from L1 — unchanged |
| `lib/layer3_comm/layer3_comm.h` | IR ball + switches from L3 — unchanged |

## 2025 Reference Files

All under `ducc/robocup-2025/open/software design/microcontrollers/src/teensy1/`:

| File | What to look at |
|---|---|
| `main.cpp` | `striker()`, `goalie()`, main loop task switch |
| `main.h` | `Robot` class, `MoveData`, `LineData` structs |
| `algorithm.cpp` | `orbitToBall()`, `orbitScore()`, `scoringStrategyOne()`, `defendGoal()` |
| `robot.cpp` | `goalieTrack()`, `goalieRush()`, `moveToPoint()`, `rejectLine()` |
| `camera.cpp` | `storeRobotPose()` localisation (we already have this) |
| `base.cpp` | Motor control, PID heading hold (we already have this) |
| `serial.cpp` | Serial handlers, ball distance regression |

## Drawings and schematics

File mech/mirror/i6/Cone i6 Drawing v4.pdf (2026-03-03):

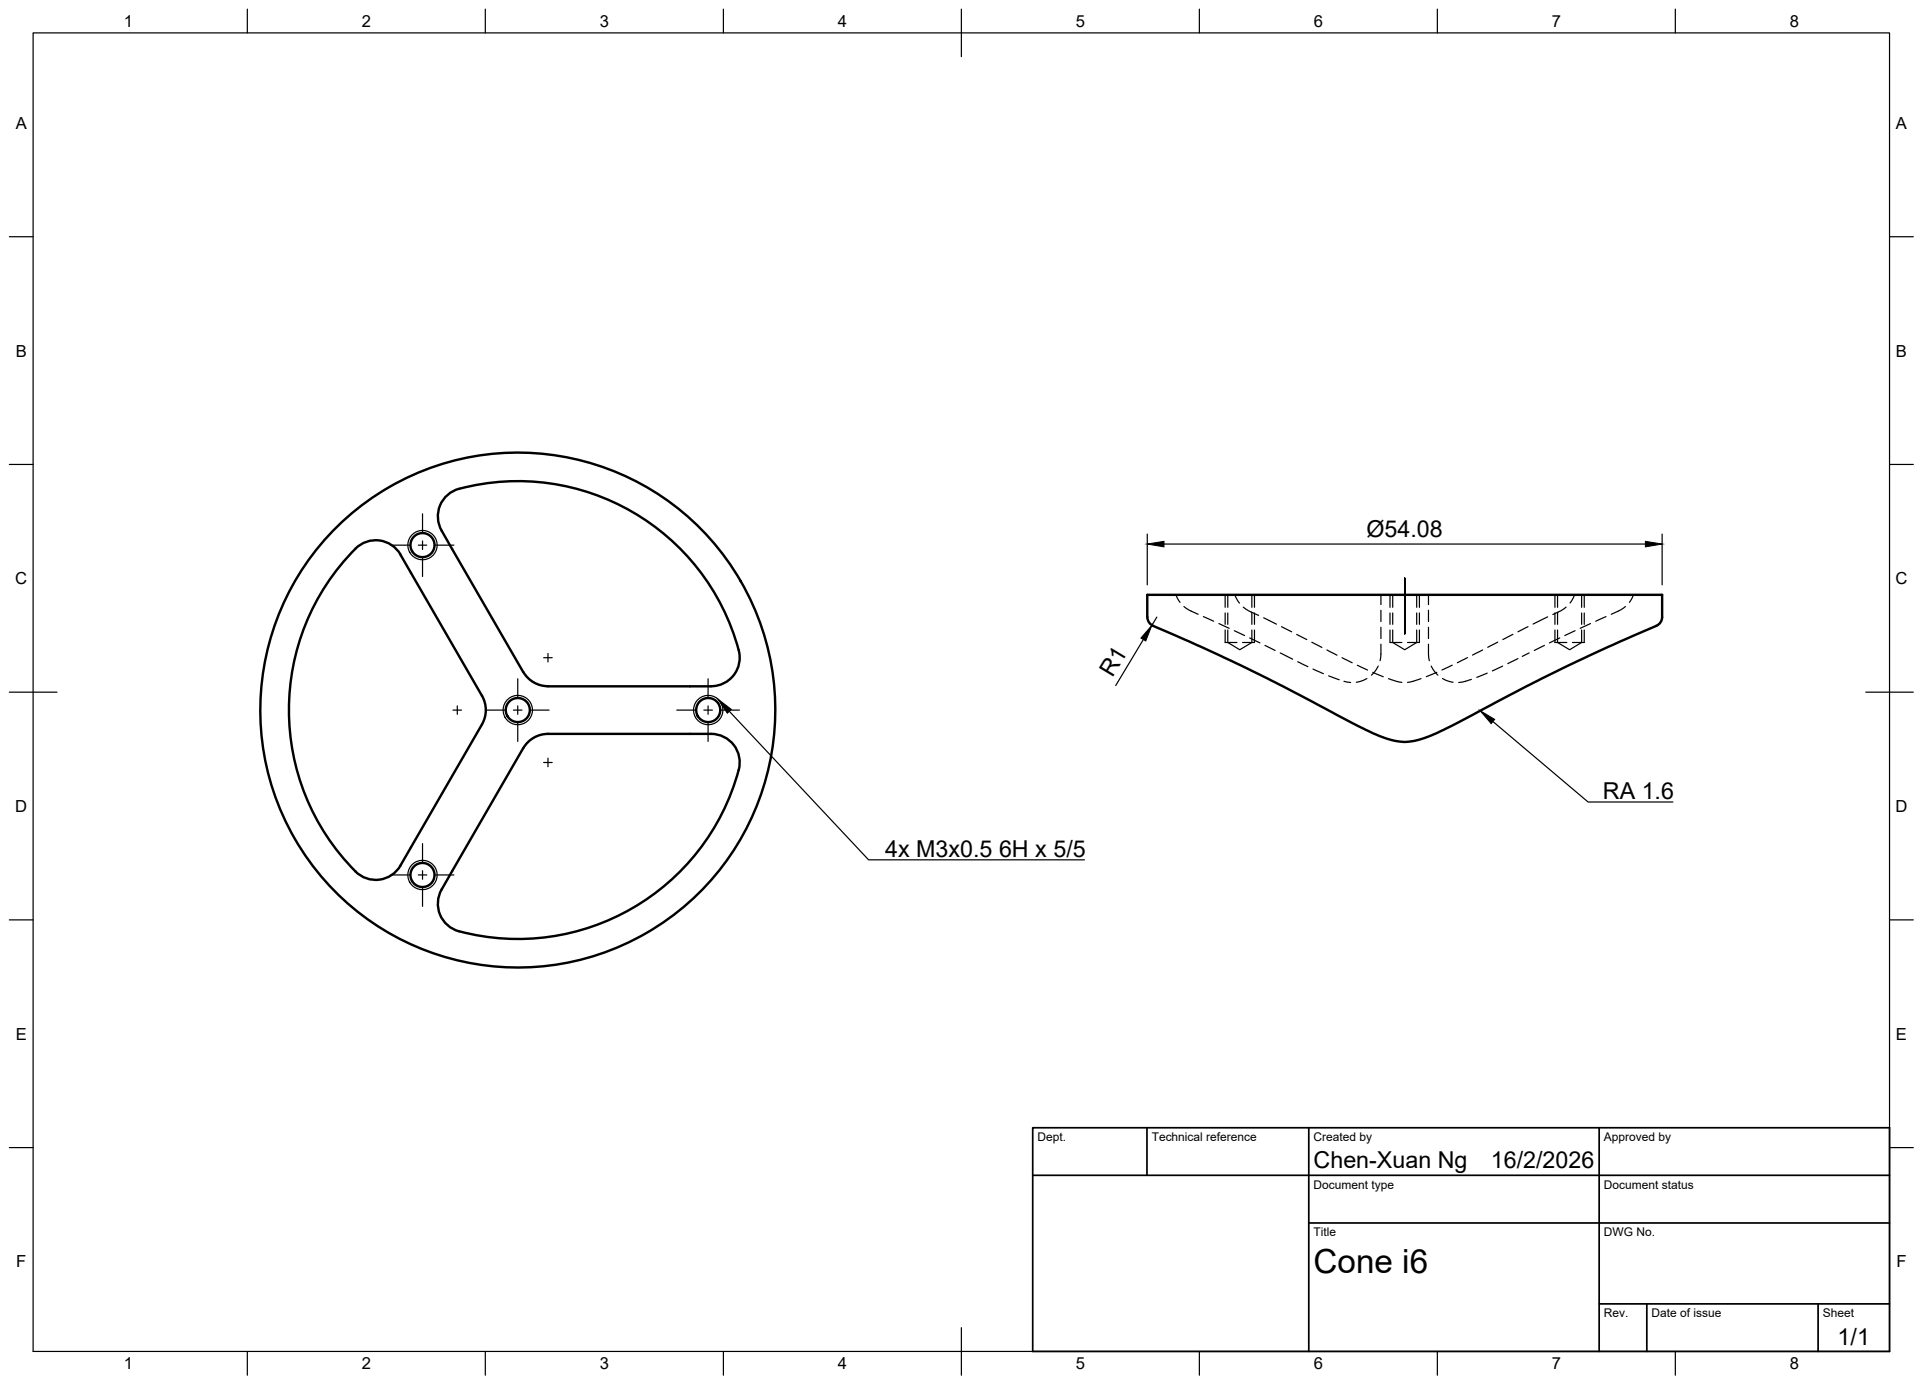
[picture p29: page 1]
Title; DWG No.; Rev.; Date of issue; Sheet; Cone i6

Dept. | Technical reference | Created by Chen-Xuan Ng 16/2/2026 | Approved by

Document type | Document status

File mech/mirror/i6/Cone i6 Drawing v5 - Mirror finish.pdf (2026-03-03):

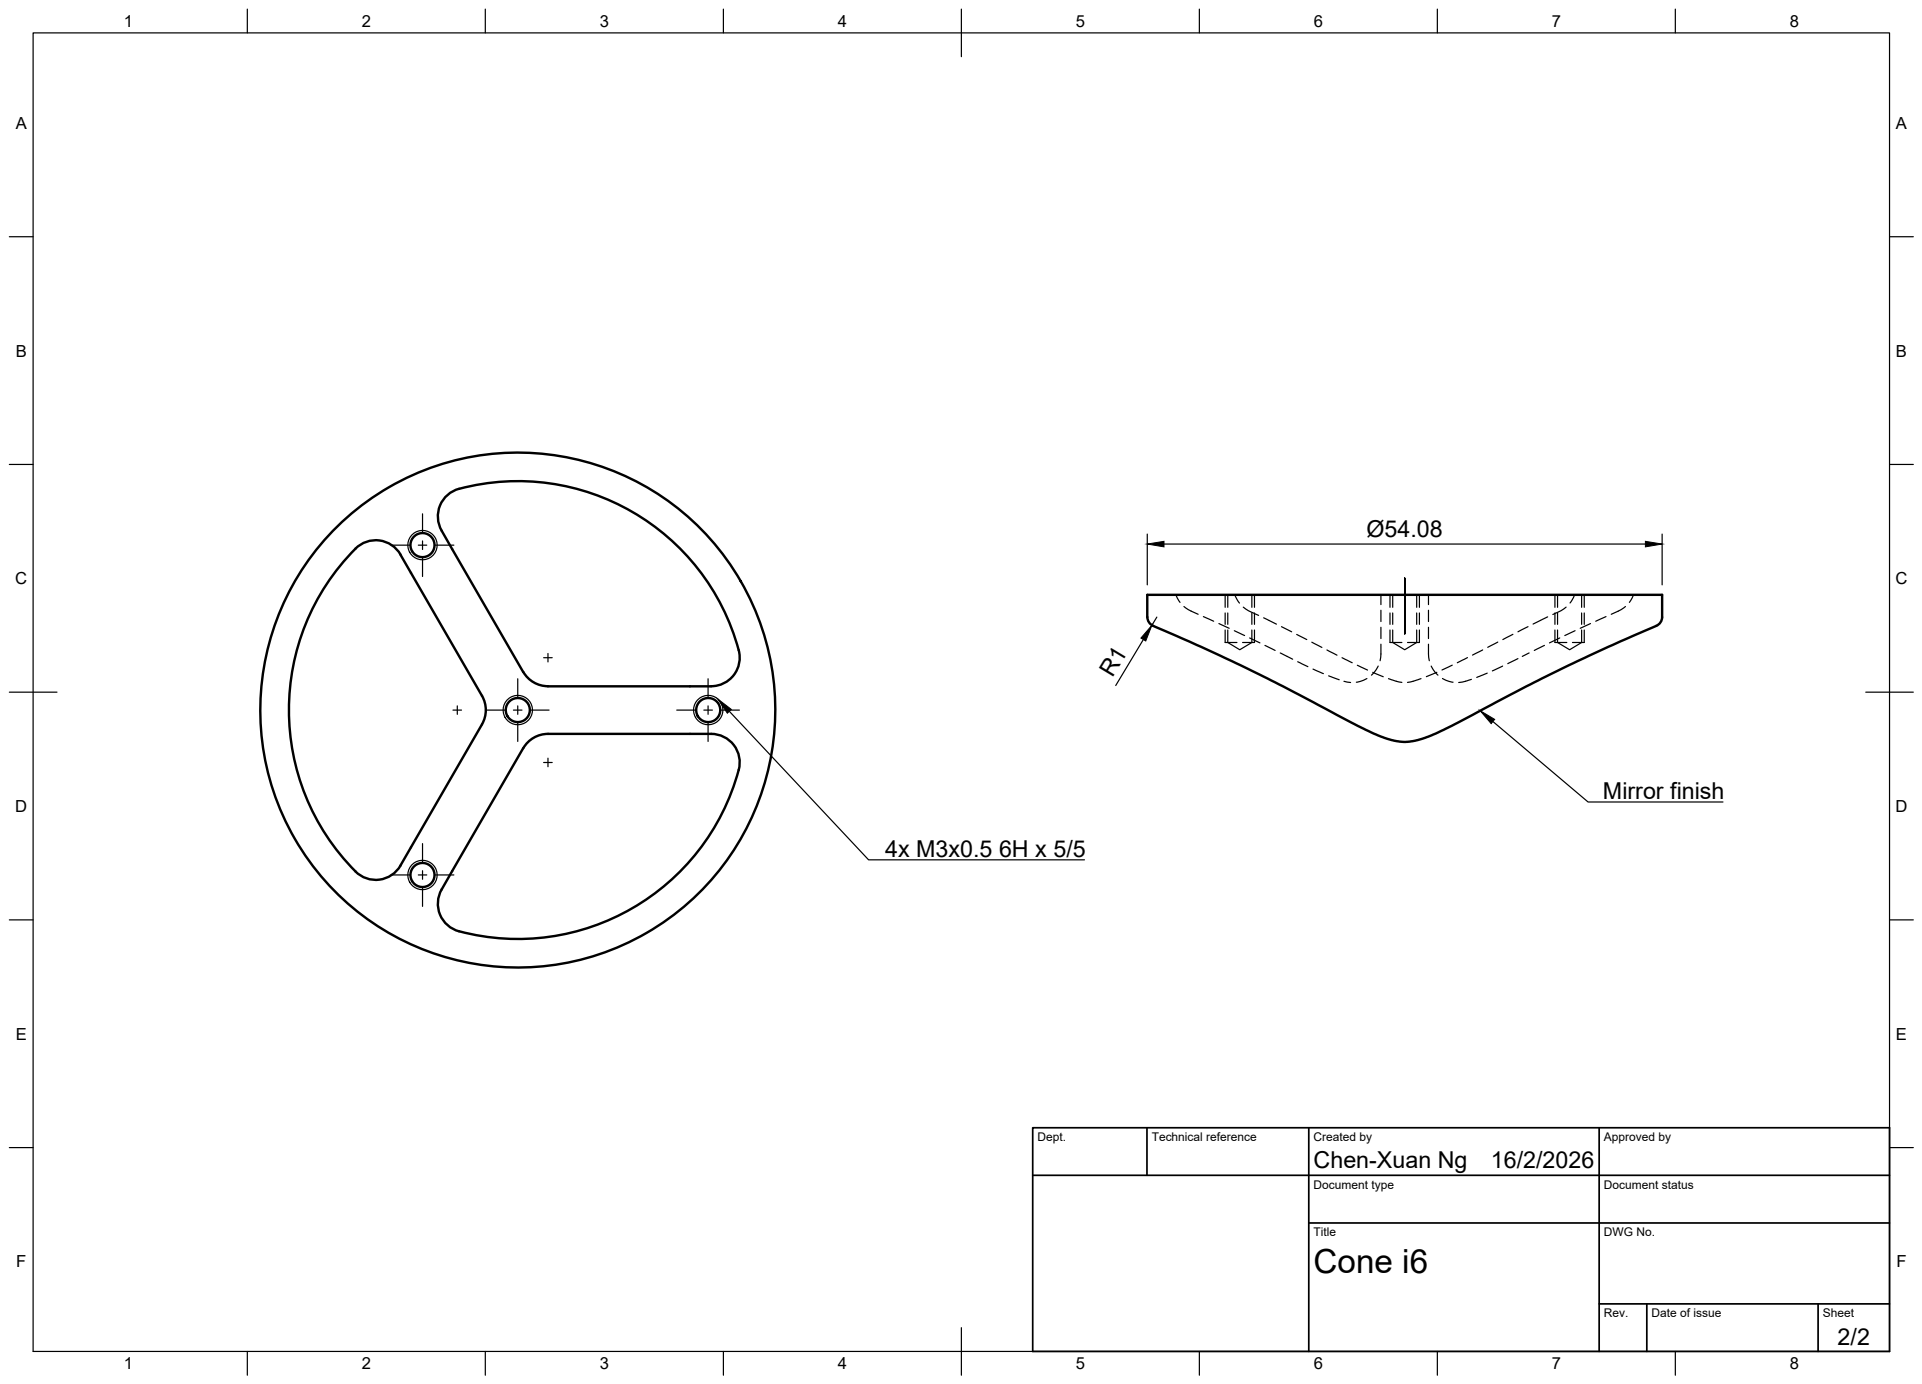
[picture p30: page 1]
Title; DWG No.; Rev.; Date of issue; Sheet; Cone i6; Mirror finish

Dept. | Technical reference | Created by Chen-Xuan Ng 16/2/2026 | Approved by

Document type | Document status

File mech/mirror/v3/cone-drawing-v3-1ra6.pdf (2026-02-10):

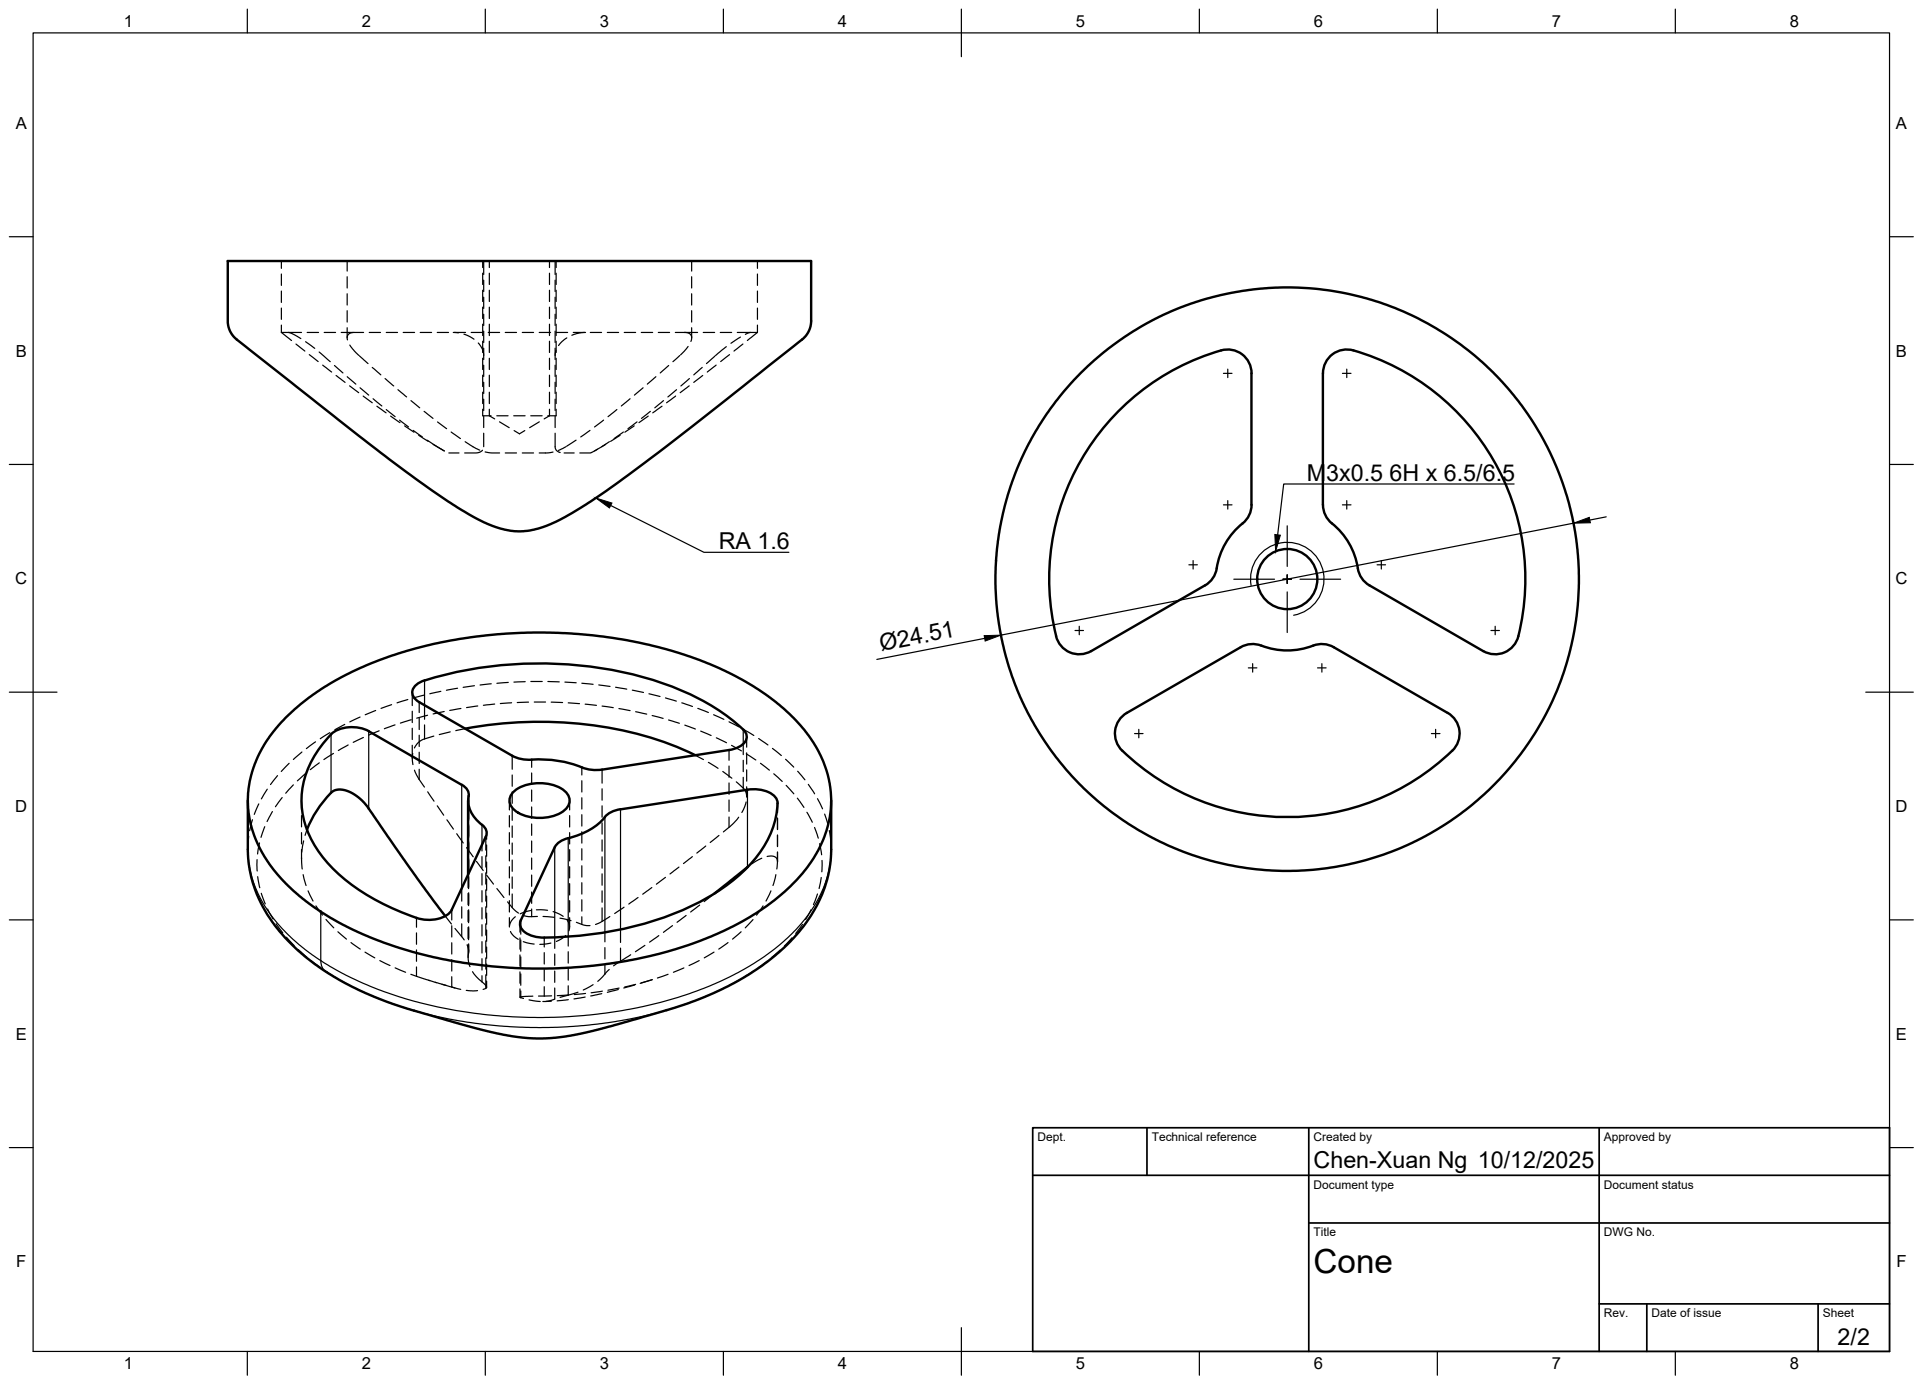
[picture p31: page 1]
Title; DWG No.; Rev.; Date of issue; Sheet

Dept. | Technical reference | Created by Chen-Xuan Ng 10/12/2025 | Approved by

Document type | Document status

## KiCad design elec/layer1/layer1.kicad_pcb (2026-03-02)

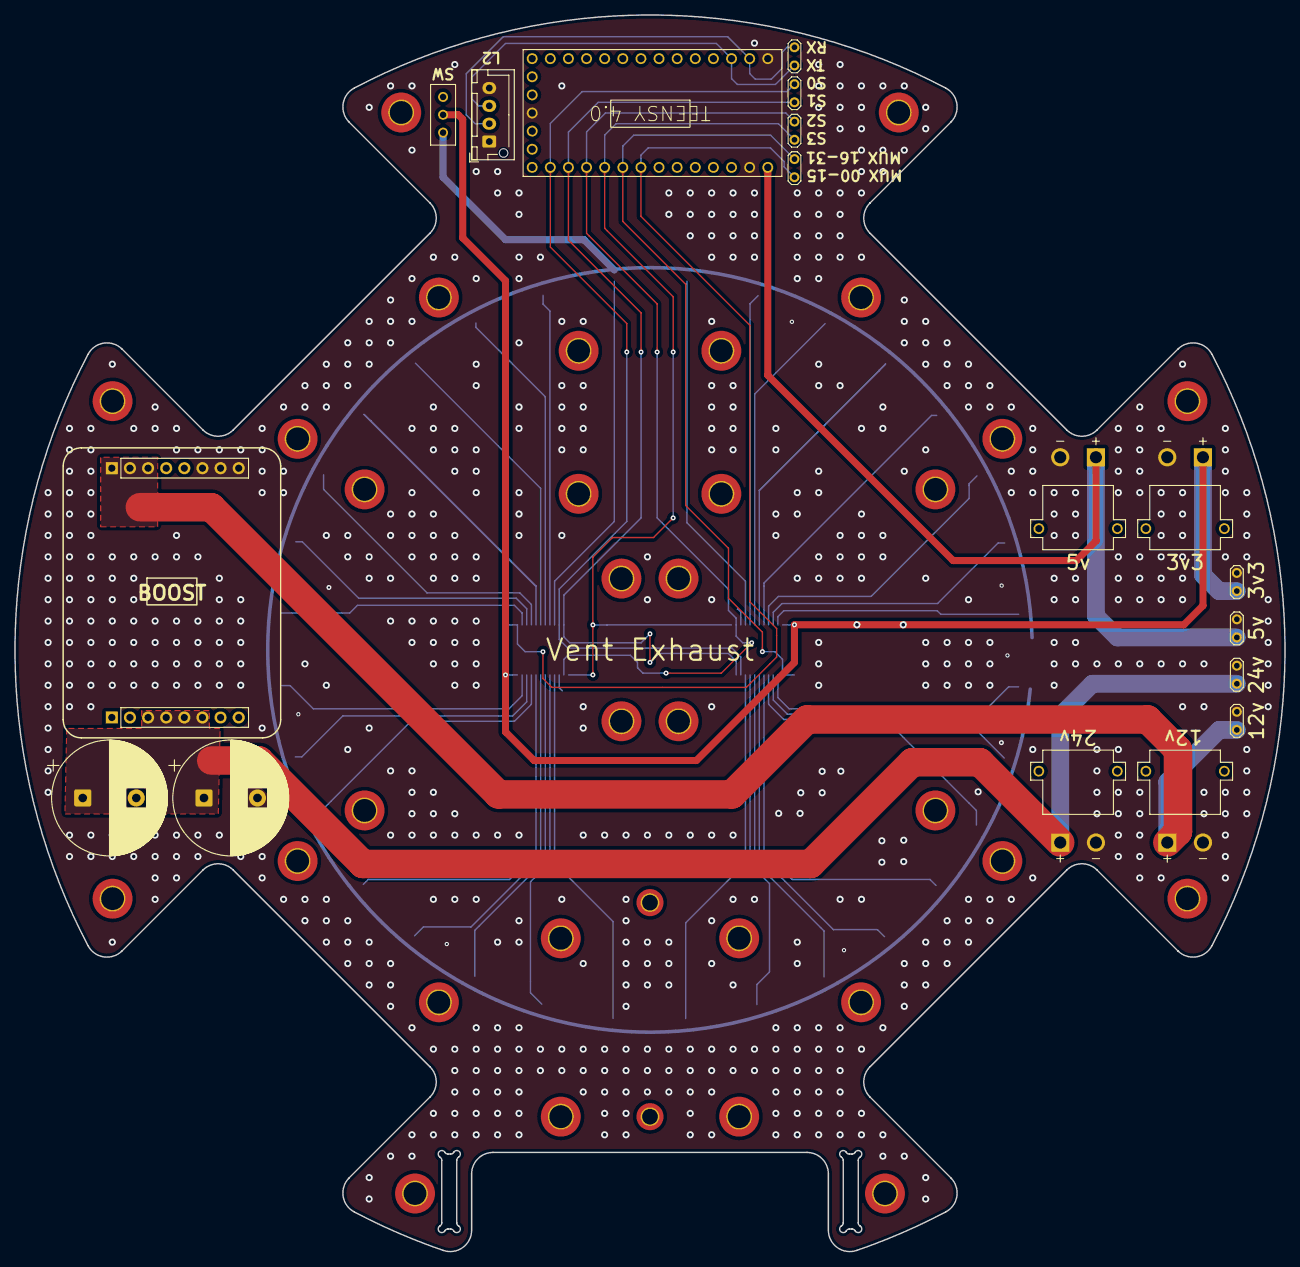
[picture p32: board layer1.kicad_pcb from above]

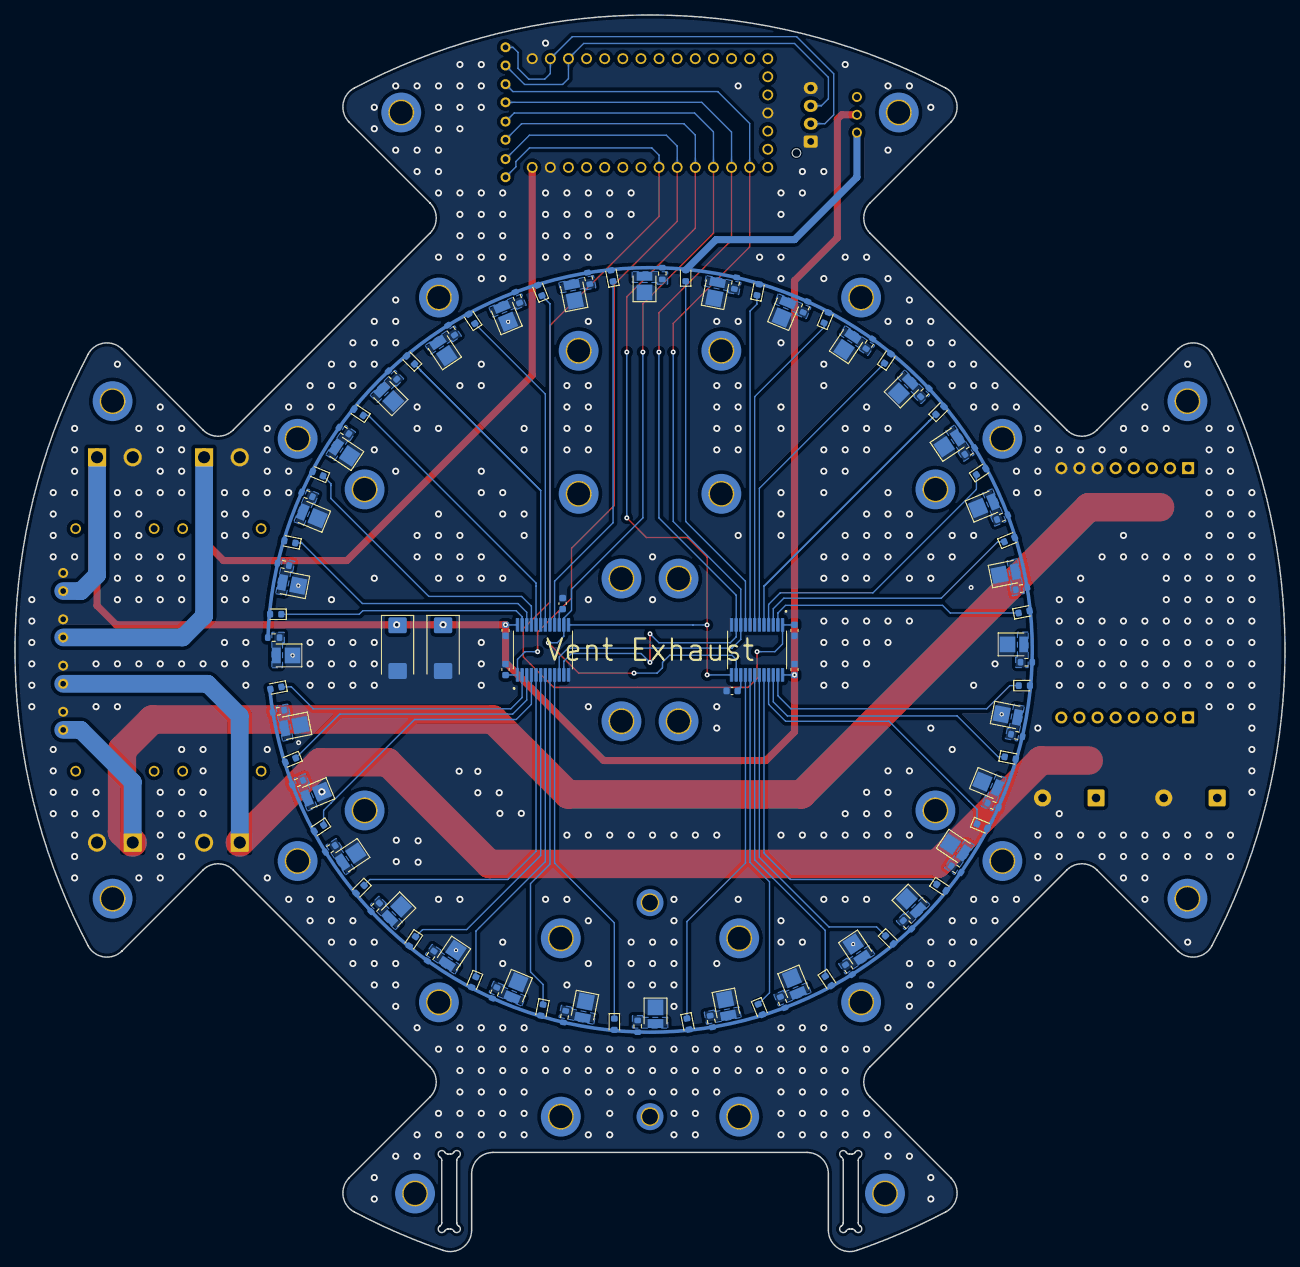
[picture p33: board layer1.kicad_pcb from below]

Board: 2 copper layers, 178.0 x 173.3 mm, 158 parts (106 on the bottom side), 80 nets.

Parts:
C1, C2: 100nF; C_0603_1608Metric
C3, C4: 1000uF; CP_Radial_D16.0mm_P7.50mm
C5, C6: 220u; CP_EIA-7343-15_Kemet-W_HandSolder
D1, D96, D97, D98, D99, D100, D101, D102, D103, D104, D105, D106, D107, D108, D109, D110, D111, D112, D113, D114, D115, D116, D117, D118, D119, D120, D121, D122, D123, D124, D125, D126: LED; LED_PLCC_2835
D33, D65, D66, D67, D68, D69, D70, D71, D72, D73, D74, D75, D76, D77, D78, D79, D80, D81, D82, D83, D84, D85, D86, D87, D88, D89, D90, D91, D92, D93, D94, D95: D_Photo; D_0603_1608Metric
H1, H2, H3, H4, H5, H6, H7, H8, H9, H10, H11, H12, H13, H14, H15, H16, H17, H18, H19, H20, H21, H22, H23, H24, H25, H26, H27, H28, H29, H30, H31, H32: MountingHole; MountingHole_3.2mm_M3_DIN965_Pad_TopBottom
H33, H34: MountingHole; MountingHole_2.2mm_M2_DIN965_Pad_TopBottom
J1, J2, J4, J5: XT30PW-M; AMASS_XT30PW-M
J3: Conn_01x04; JST_XH_B4B-XH-AM_1x04_P2.50mm_Vertical
R1, R4: 10k; C_0603_1608Metric
R2, R3: 3k; C_0603_1608Metric
R5: 10R; R_0603_1608Metric
R37, R38, R39, R40, R41, R42, R43, R44, R45, R46, R47, R48, R49, R50, R51, R52, R53, R54, R55, R56, R57, R58, R59, R60, R61, R62, R63, R64, R65, R66, R67: 0R39; R_0603_1608Metric
SW2: SW_SPDT_312; SS12D00G3
TP1, TP2, TP3, TP4, TP5, TP6, TP7, TP8: TestPoint_2Pole; TestPoint_2Pads_Pitch2.54mm_Drill0.8mm
U1, U2: CD74HC4067SM
U3: TEENSY40
U4: boost-module

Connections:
3v3 - LED, Photodiode: D33.2 (A), D65.2 (A), D66.2 (A), D67.2 (A), D68.2 (A), D69.2 (A), D70.2 (A), D71.2 (A), D72.2 (A), D73.2 (A), D74.2 (A), D75.2 (A), D76.2 (A), D77.2 (A), D78.2 (A), D79.2 (A), D80.2 (A), D81.2 (A), D82.2 (A), D83.2 (A), D84.2 (A), D85.2 (A), D86.2 (A), D87.2 (A), D88.2 (A), D89.2 (A), D90.2 (A), D91.2 (A), D92.2 (A), D93.2 (A), D94.2 (A), D95.2 (A), R5.1, R37.1, R38.1, R39.1, R40.1, R41.1, R42.1, R43.1, R44.1, R45.1, R46.1, R47.1, R48.1, R49.1, R50.1, R51.1, R52.1, R53.1, R54.1, R55.1, R56.1, R57.1, R58.1, R59.1, R60.1, R61.1, R62.1, R63.1, R64.1, R65.1, R66.1, R67.1, SW2.3 (A)
+3V3: C1.1, C2.1, C5.1, C6.1, J1.P, SW2.1 (B), TP1.1, U1.24 (VCC), U2.24 (VCC)
+5V: J2.P, TP2.1, U3.VIN
+12V: J5.P, TP3.1, U4.1 (Vin)
+24V: C3.1, C4.1, J4.P, TP8.1, U4.4 (Vout)
/Mux Com (0-15): R2.1, TP5.1, U1.1 (COM), U3.19
/Mux Com (16-31): R3.1, TP5.2, U2.1 (COM), U3.18
/RX (L1-Teensy): J3.2, TP4.1, U3.0
/S0: TP6.2, U1.10 (S0), U2.10 (S0), U3.14
/S1: TP6.1, U1.11 (S1), U2.11 (S1), U3.15
/S2: TP7.2, U1.14 (S2), U2.14 (S2), U3.16
/S3: TP7.1, U1.13 (S3), U2.13 (S3), U3.17
/TX (L1-Teensy): J3.3, TP4.2, U3.1
GND: C1.2, C2.2, C3.2, C4.2, C5.2, C6.2, D1.1 (K), D96.1 (K), D97.1 (K), D98.1 (K), D99.1 (K), D100.1 (K), D101.1 (K), D102.1 (K), D103.1 (K), D104.1 (K), D105.1 (K), D106.1 (K), D107.1 (K), D108.1 (K), D109.1 (K), D110.1 (K), D111.1 (K), D112.1 (K), D113.1 (K), D114.1 (K), D115.1 (K), D116.1 (K), D117.1 (K), D118.1 (K), D119.1 (K), D120.1 (K), D121.1 (K), D122.1 (K), D123.1 (K), D124.1 (K), D125.1 (K), D126.1 (K), J1.N, J2.N, J3.1, J3.4, J4.N, J5.N, R1.2, R2.2, R3.2, R4.2, TP1.2, TP2.2, TP3.2, TP8.2, U1.12 (GND), U2.12 (GND), U3.G1, U3.G2, U3.G3, U4.3 (GND)
unnamed: D1.2 (A), R5.2
unnamed: D96.2 (A), R37.2
unnamed: D97.2 (A), R38.2
unnamed: D98.2 (A), R39.2
unnamed: D99.2 (A), R40.2
unnamed: D100.2 (A), R41.2
unnamed: D101.2 (A), R42.2
unnamed: D102.2 (A), R43.2
unnamed: D103.2 (A), R44.2
unnamed: D104.2 (A), R45.2
unnamed: D105.2 (A), R46.2
unnamed: D106.2 (A), R47.2
unnamed: D107.2 (A), R48.2
unnamed: D108.2 (A), R49.2
unnamed: D109.2 (A), R50.2
unnamed: D110.2 (A), R51.2
unnamed: D111.2 (A), R52.2
unnamed: D112.2 (A), R53.2
unnamed: D113.2 (A), R54.2
unnamed: D114.2 (A), R55.2
unnamed: D115.2 (A), R56.2
unnamed: D116.2 (A), R57.2
unnamed: D117.2 (A), R58.2
unnamed: D118.2 (A), R59.2
unnamed: D119.2 (A), R60.2
unnamed: D120.2 (A), R61.2
unnamed: D121.2 (A), R62.2
unnamed: D122.2 (A), R63.2
unnamed: D123.2 (A), R64.2
unnamed: D124.2 (A), R65.2
unnamed: D125.2 (A), R66.2
unnamed: D126.2 (A), R67.2
unnamed: D33.1 (K), U1.9 (I0)
unnamed: D65.1 (K), U1.8 (I1)
unnamed: D66.1 (K), U1.7 (I2)
unnamed: D67.1 (K), U1.6 (I3)
unnamed: D68.1 (K), U1.5 (I4)
unnamed: D69.1 (K), U1.4 (I5)
unnamed: D70.1 (K), U1.3 (I6)
unnamed: D71.1 (K), U1.2 (I7)
unnamed: D72.1 (K), U1.23 (I8)
unnamed: D73.1 (K), U1.22 (I9)
unnamed: D74.1 (K), U1.21 (I10)
unnamed: D75.1 (K), U1.20 (I11)
unnamed: D76.1 (K), U1.19 (I12)
unnamed: D77.1 (K), U1.18 (I13)
unnamed: D78.1 (K), U1.17 (I14)
unnamed: D79.1 (K), U1.16 (I15)
unnamed: D80.1 (K), U2.9 (I0)
unnamed: D81.1 (K), U2.8 (I1)
unnamed: D82.1 (K), U2.7 (I2)
unnamed: D83.1 (K), U2.6 (I3)
unnamed: D84.1 (K), U2.5 (I4)
unnamed: D85.1 (K), U2.4 (I5)
unnamed: D86.1 (K), U2.3 (I6)
unnamed: D87.1 (K), U2.2 (I7)
unnamed: D88.1 (K), U2.23 (I8)
unnamed: D89.1 (K), U2.22 (I9)
unnamed: D90.1 (K), U2.21 (I10)
unnamed: D91.1 (K), U2.20 (I11)
unnamed: D92.1 (K), U2.19 (I12)
unnamed: D93.1 (K), U2.18 (I13)
unnamed: D94.1 (K), U2.17 (I14)
unnamed: D95.1 (K), U2.16 (I15)
unnamed: R1.1, U1.15 (~E)
unnamed: R4.1, U2.15 (~E)

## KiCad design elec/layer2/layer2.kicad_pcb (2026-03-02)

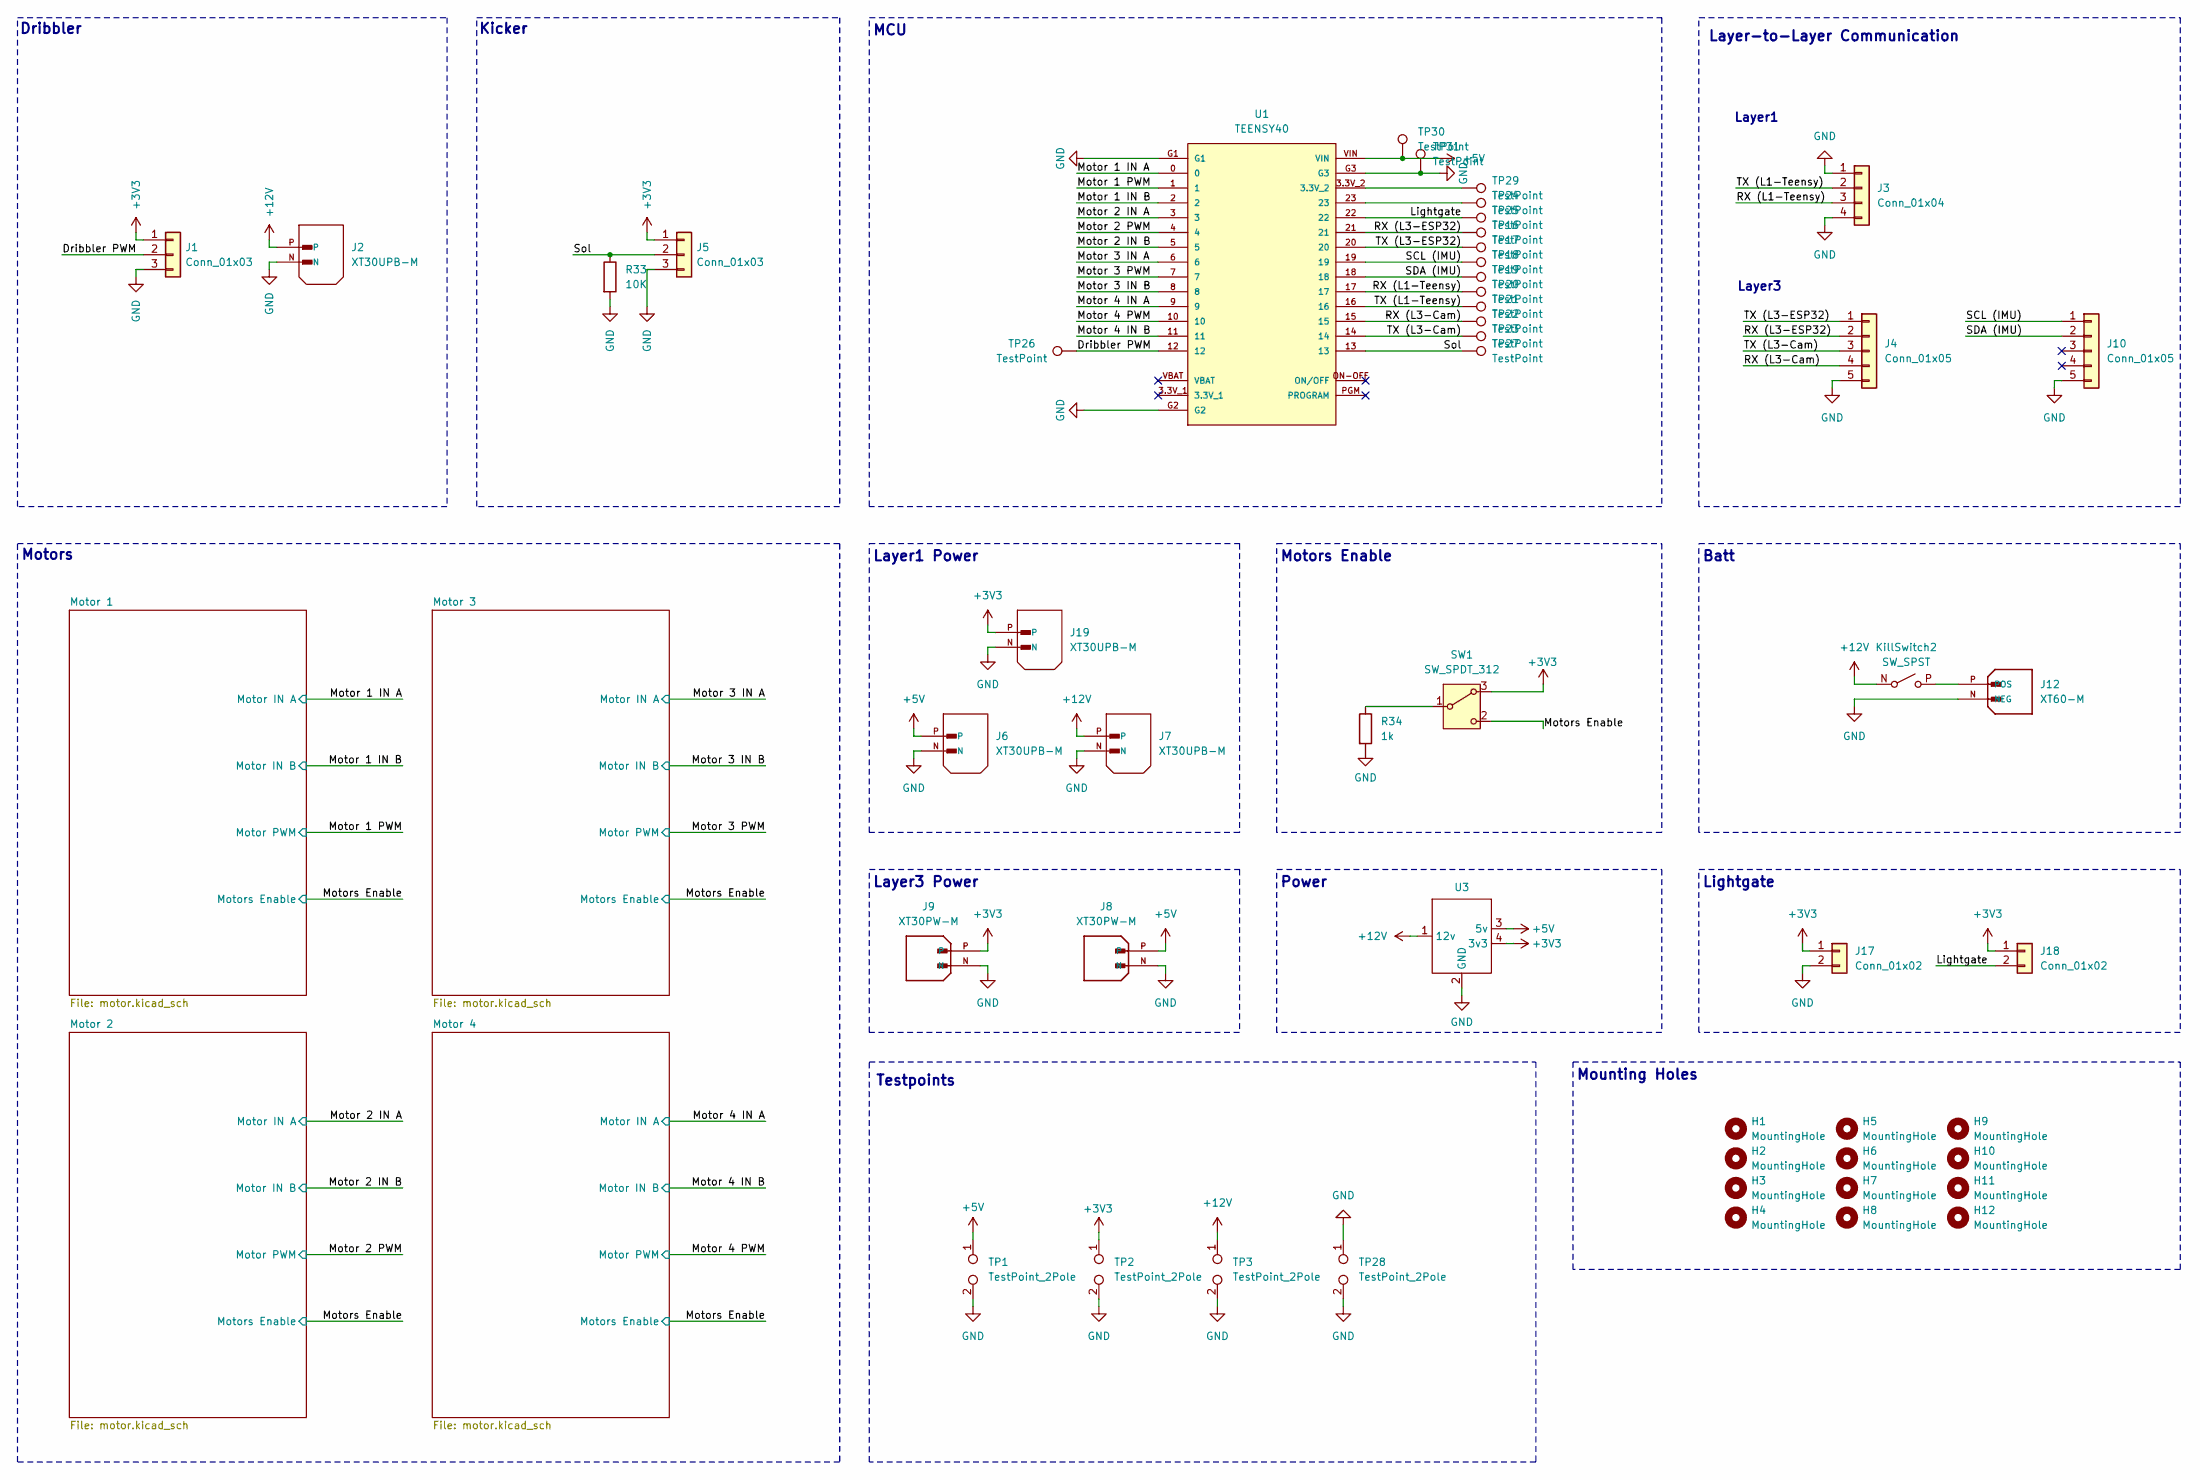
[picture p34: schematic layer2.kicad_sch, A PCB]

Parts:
H1, H2, H3, H4, H5, H6, H7, H8, H9, H10, H11, H12: MountingHole; MountingHole_3.2mm_M3_DIN965_Pad
J1, J5: Conn_01x03; JST_XH_B3B-XH-A_1x03_P2.50mm_Vertical
J2, J6, J7, J19: XT30UPB-M; AMASS_XT30UPB-M
J3: Conn_01x04; JST_XH_B4B-XH-A_1x04_P2.50mm_Vertical
J4, J10: Conn_01x05; JST_XH_B5B-XH-A_1x05_P2.50mm_Vertical
J8, J9: XT30PW-M; AMASS_XT30PW-M; PARTREV 1.2
J12: XT60-M; AMASS_XT60-M; PARTREV V1.2
J17, J18: Conn_01x02; JST_XH_B2B-XH-A_1x02_P2.50mm_Vertical
KillSwitch2: SW_SPST; AMASS_XT30UPB-M
R33: 10K; R_0603_1608Metric
R34: 1k; R_0603_1608Metric
SW1: SW_SPDT_312; SS12D00G3
TP1, TP2, TP3, TP28: TestPoint_2Pole; TestPoint_2Pads_Pitch2.54mm_Drill0.8mm
TP16, TP17, TP18, TP19, TP20, TP21, TP22, TP23, TP24, TP25, TP26, TP27, TP29, TP30, TP31: TestPoint; TestPoint_THTPad_D1.5mm_Drill0.7mm
U1: TEENSY40
U3: buck-module

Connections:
+3V3: J1.1, J5.1, J9.P, J17.1, J18.1, J19.P, SW1.3 (A), TP2.1, U3.4 (3v3); also elsewhere on the board
+5V: J6.P, J8.P, TP1.1, TP30.1, U1.VIN, U3.3 (5v)
+12V: J2.P, J7.P, KillSwitch2.N (A), TP3.1, U3.1 (12v); also elsewhere on the board
/Dribbler PWM: J1.2, TP26.1, U1.12
/Lightgate: J18.2, TP25.1, U1.22
/Motor 1 IN A: U1.0; also elsewhere on the board
/Motor 1 IN B: U1.2; also elsewhere on the board
/Motor 1 PWM: U1.1; also elsewhere on the board
/Motor 2 IN A: U1.3; also elsewhere on the board
/Motor 2 IN B: U1.5; also elsewhere on the board
/Motor 2 PWM: U1.4; also elsewhere on the board
/Motor 3 IN A: U1.6; also elsewhere on the board
/Motor 3 IN B: U1.8; also elsewhere on the board
/Motor 3 PWM: U1.7; also elsewhere on the board
/Motor 4 IN A: U1.9; also elsewhere on the board
/Motor 4 IN B: U1.11; also elsewhere on the board
/Motor 4 PWM: U1.10; also elsewhere on the board
/Motors Enable: SW1.2 (C); also elsewhere on the board
/RX (L1-Teensy): J3.3, TP20.1, U1.17
/RX (L3-Cam): J4.4, TP22.1, U1.15
/RX (L3-ESP32): J4.2, TP16.1, U1.21
/SCL (IMU): J10.1, TP18.1, U1.19
/SDA (IMU): J10.2, TP19.1, U1.18
/Sol: J5.2, R33.1, TP27.1, U1.13
/TX (L1-Teensy): J3.2, TP21.1, U1.16
/TX (L3-Cam): J4.3, TP23.1, U1.14
/TX (L3-ESP32): J4.1, TP17.1, U1.20
GND: J1.3, J2.N, J3.1, J3.4, J4.5, J5.3, J6.N, J7.N, J8.N, J9.N, J10.5, J12.N (NEG), J17.2, J19.N, R33.2, R34.2, TP1.2, TP2.2, TP3.2, TP28.1, TP28.2, TP31.1, U1.G1, U1.G2, U1.G3, U3.2 (GND); also elsewhere on the board
unnamed: J12.P (POS), KillSwitch2.P (B)
unnamed: R34.1, SW1.1 (B)
unnamed: TP24.1, U1.23
unnamed: TP29.1, U1.3.3V_2

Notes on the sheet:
Batt
Mounting Holes
Lightgate
Layer1
Power
Kicker
Dribbler
Motors
Testpoints
MCU
Layer3
Layer1 Power
Motors Enable
Layer-to-Layer Communication
Layer3 Power

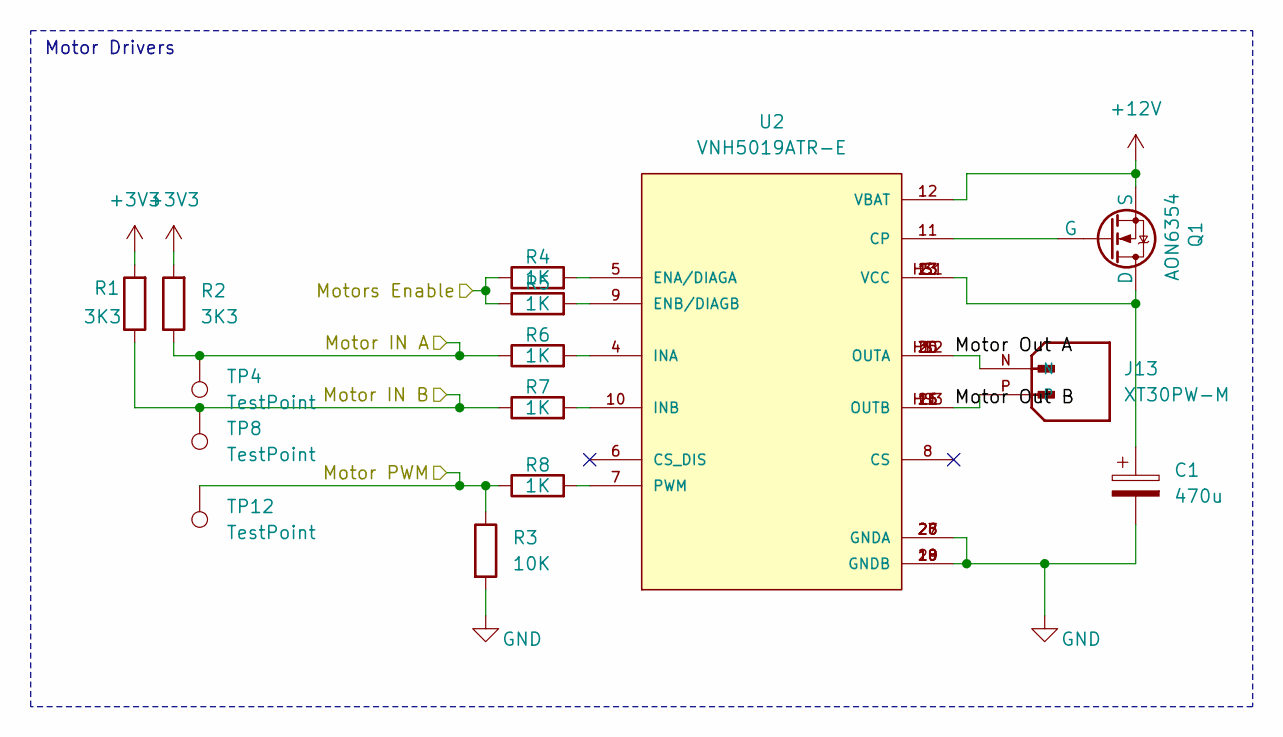
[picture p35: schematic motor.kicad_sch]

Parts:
C1: 470u; CP_Radial_D8.0mm_P3.50mm; LCSC C5162352
J13: XT30PW-M; AMASS_XT30PW-M; PARTREV 1.2
Q1: AON6354; 8-DFN (5x6)
R1, R2: 3K3; R_0603_1608Metric
R3: 10K; R_0603_1608Metric
R4, R5, R6, R7, R8: 1K; R_0603_1608Metric
TP4, TP8, TP12: TestPoint; TestPoint_THTPad_D1.5mm_Drill0.7mm
U2: VNH5019ATR-E; PARTREV 11

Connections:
+3V3: R1.2, R2.2; also elsewhere on the board
+12V: Q1.1 (S), Q1.2 (S), Q1.3 (S), U2.12 (VBAT); also elsewhere on the board
/Motor 1 IN A: R2.1, R6.1, TP4.1; also elsewhere on the board
/Motor 1 IN B: R1.1, R7.1, TP8.1; also elsewhere on the board
/Motor 1 PWM: R3.1, R8.1, TP12.1; also elsewhere on the board
/Motor 1/Motor Out A: J13.N, U2.1 (OUTA), U2.25 (OUTA), U2.30 (OUTA), U2.HS2 (OUTA)
/Motor 1/Motor Out B: J13.P, U2.15 (OUTB), U2.16 (OUTB), U2.21 (OUTB), U2.HS3 (OUTB)
/Motors Enable: R4.1, R5.1; also elsewhere on the board
GND: C1.2, R3.2, U2.18 (GNDB), U2.19 (GNDB), U2.20 (GNDB), U2.26 (GNDA), U2.27 (GNDA), U2.28 (GNDA); also elsewhere on the board
unnamed: C1.1, Q1.5 (D), Q1.6 (D), Q1.7 (D), Q1.8 (D), Q1.9 (D), U2.3 (VCC), U2.13 (VCC), U2.23 (VCC), U2.HS1 (VCC)
unnamed: Q1.4 (G), U2.11 (CP)
unnamed: R4.2, U2.5 (ENA/DIAGA)
unnamed: R5.2, U2.9 (ENB/DIAGB)
unnamed: R6.2, U2.4 (INA)
unnamed: R7.2, U2.10 (INB)
unnamed: R8.2, U2.7 (PWM)

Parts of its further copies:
C2, C3, C4: 470u; CP_Radial_D8.0mm_P3.50mm; LCSC C5162352
J14, J15, J16: XT30PW-M; AMASS_XT30PW-M; PARTREV 1.2
Q2, Q3, Q4: AON6354; 8-DFN (5x6)
R9, R10, R17, R18, R25, R26: 3K3; R_0603_1608Metric
R11, R19, R27: 10K; R_0603_1608Metric
R12, R13, R14, R15, R16, R20, R21, R22, R23, R24, R28, R29, R30, R31, R32: 1K; R_0603_1608Metric
TP5, TP6, TP7, TP9, TP10, TP11, TP13, TP14, TP15: TestPoint; TestPoint_THTPad_D1.5mm_Drill0.7mm
U4, U6, U8: VNH5019ATR-E; PARTREV 11

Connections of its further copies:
+3V3: R9.2, R10.2, R17.2, R18.2, R25.2, R26.2; also elsewhere on the board
+12V: Q2.1 (S), Q2.2 (S), Q2.3 (S), Q3.1 (S), Q3.2 (S), Q3.3 (S), Q4.1 (S), Q4.2 (S), Q4.3 (S), U4.12 (VBAT), U6.12 (VBAT), U8.12 (VBAT); also elsewhere on the board
/Motor 2 IN A: R10.1, R14.1, TP5.1; also elsewhere on the board
/Motor 2 IN B: R9.1, R15.1, TP9.1; also elsewhere on the board
/Motor 2 PWM: R11.1, R16.1, TP13.1; also elsewhere on the board
/Motor 2/Motor Out A: J14.N, U4.1 (OUTA), U4.25 (OUTA), U4.30 (OUTA), U4.HS2 (OUTA)
/Motor 2/Motor Out B: J14.P, U4.15 (OUTB), U4.16 (OUTB), U4.21 (OUTB), U4.HS3 (OUTB)
/Motor 3 IN A: R18.1, R22.1, TP6.1; also elsewhere on the board
/Motor 3 IN B: R17.1, R23.1, TP10.1; also elsewhere on the board
/Motor 3 PWM: R19.1, R24.1, TP14.1; also elsewhere on the board
/Motor 3/Motor Out A: J15.N, U6.1 (OUTA), U6.25 (OUTA), U6.30 (OUTA), U6.HS2 (OUTA)
/Motor 3/Motor Out B: J15.P, U6.15 (OUTB), U6.16 (OUTB), U6.21 (OUTB), U6.HS3 (OUTB)
/Motor 4 IN A: R26.1, R30.1, TP7.1; also elsewhere on the board
/Motor 4 IN B: R25.1, R31.1, TP11.1; also elsewhere on the board
/Motor 4 PWM: R27.1, R32.1, TP15.1; also elsewhere on the board
/Motor 4/Motor Out A: J16.N, U8.1 (OUTA), U8.25 (OUTA), U8.30 (OUTA), U8.HS2 (OUTA)
/Motor 4/Motor Out B: J16.P, U8.15 (OUTB), U8.16 (OUTB), U8.21 (OUTB), U8.HS3 (OUTB)
/Motors Enable: R12.1, R13.1, R20.1, R21.1, R28.1, R29.1; also elsewhere on the board
GND: C2.2, C3.2, C4.2, R11.2, R19.2, R27.2, U4.18 (GNDB), U4.19 (GNDB), U4.20 (GNDB), U4.26 (GNDA), U4.27 (GNDA), U4.28 (GNDA), U6.18 (GNDB), U6.19 (GNDB), U6.20 (GNDB), U6.26 (GNDA), U6.27 (GNDA), U6.28 (GNDA), U8.18 (GNDB), U8.19 (GNDB), U8.20 (GNDB), U8.26 (GNDA), U8.27 (GNDA), U8.28 (GNDA); also elsewhere on the board
unnamed: C2.1, Q2.5 (D), Q2.6 (D), Q2.7 (D), Q2.8 (D), Q2.9 (D), U4.3 (VCC), U4.13 (VCC), U4.23 (VCC), U4.HS1 (VCC)
unnamed: C3.1, Q3.5 (D), Q3.6 (D), Q3.7 (D), Q3.8 (D), Q3.9 (D), U6.3 (VCC), U6.13 (VCC), U6.23 (VCC), U6.HS1 (VCC)
unnamed: C4.1, Q4.5 (D), Q4.6 (D), Q4.7 (D), Q4.8 (D), Q4.9 (D), U8.3 (VCC), U8.13 (VCC), U8.23 (VCC), U8.HS1 (VCC)
unnamed: Q2.4 (G), U4.11 (CP)
unnamed: Q3.4 (G), U6.11 (CP)
unnamed: Q4.4 (G), U8.11 (CP)
unnamed: R12.2, U4.5 (ENA/DIAGA)
unnamed: R13.2, U4.9 (ENB/DIAGB)
unnamed: R14.2, U4.4 (INA)
unnamed: R15.2, U4.10 (INB)
unnamed: R16.2, U4.7 (PWM)
unnamed: R20.2, U6.5 (ENA/DIAGA)
unnamed: R21.2, U6.9 (ENB/DIAGB)
unnamed: R22.2, U6.4 (INA)
unnamed: R23.2, U6.10 (INB)
unnamed: R24.2, U6.7 (PWM)
unnamed: R28.2, U8.5 (ENA/DIAGA)
unnamed: R29.2, U8.9 (ENB/DIAGB)
unnamed: R30.2, U8.4 (INA)
unnamed: R31.2, U8.10 (INB)
unnamed: R32.2, U8.7 (PWM)

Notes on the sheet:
Motor Drivers

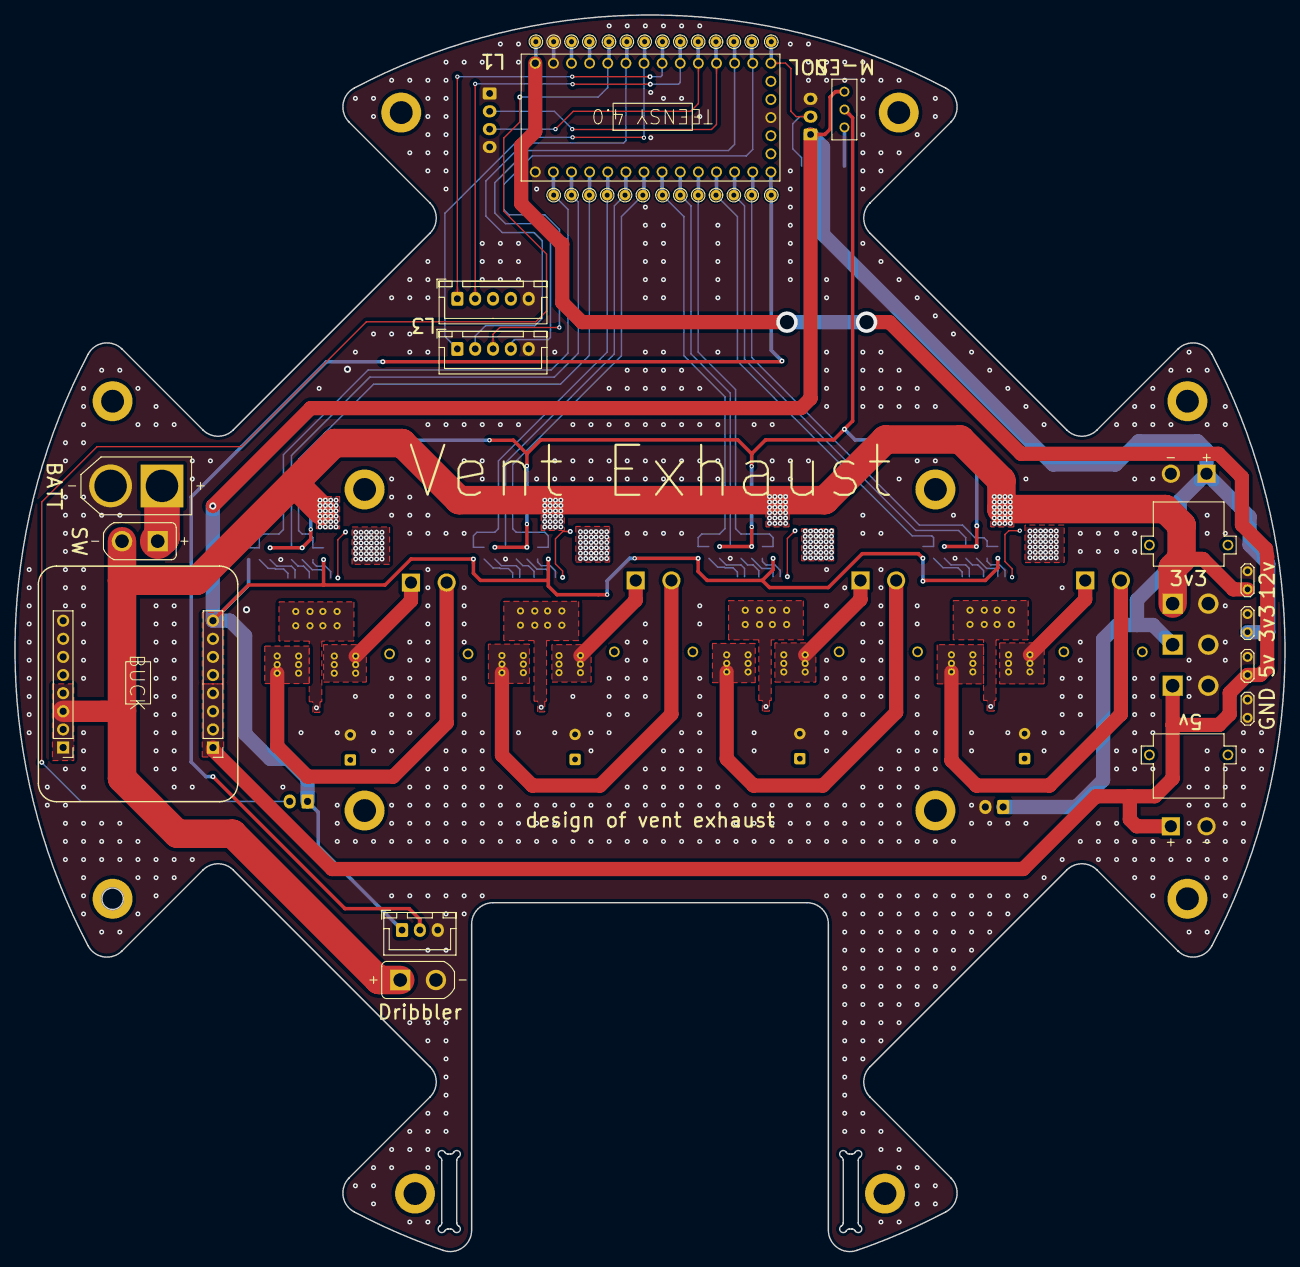
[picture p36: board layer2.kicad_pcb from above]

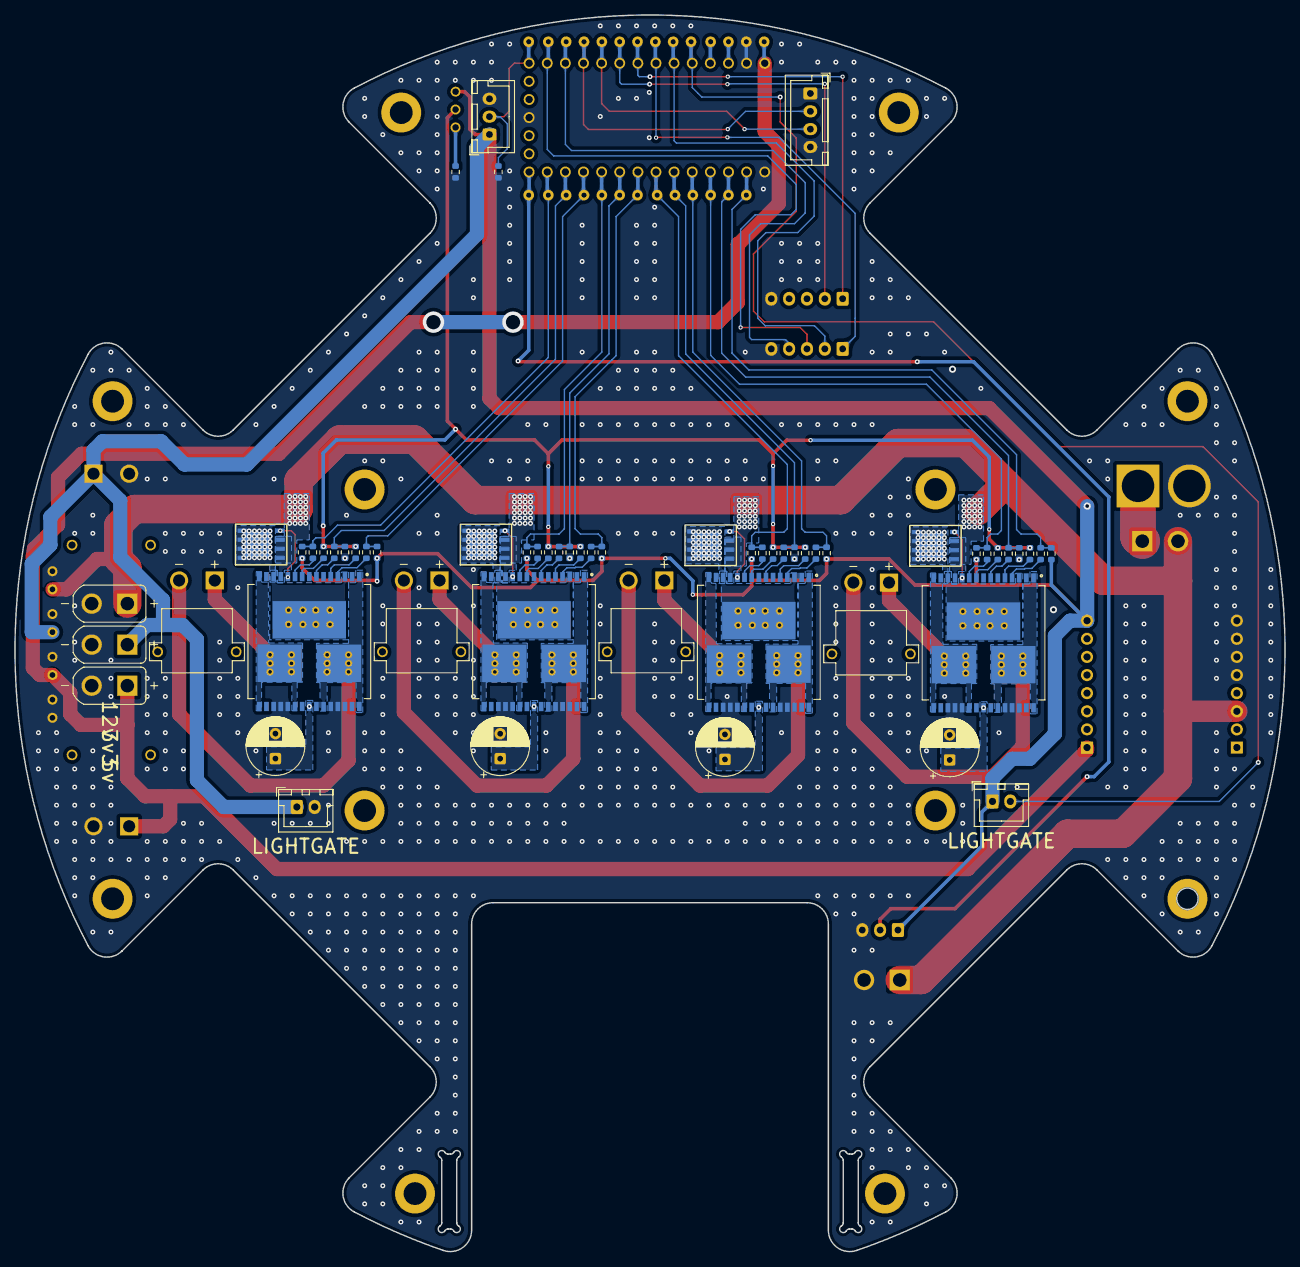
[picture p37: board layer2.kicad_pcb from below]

Board: 2 copper layers, 178.0 x 173.3 mm, 111 parts (57 on the bottom side), 68 nets.

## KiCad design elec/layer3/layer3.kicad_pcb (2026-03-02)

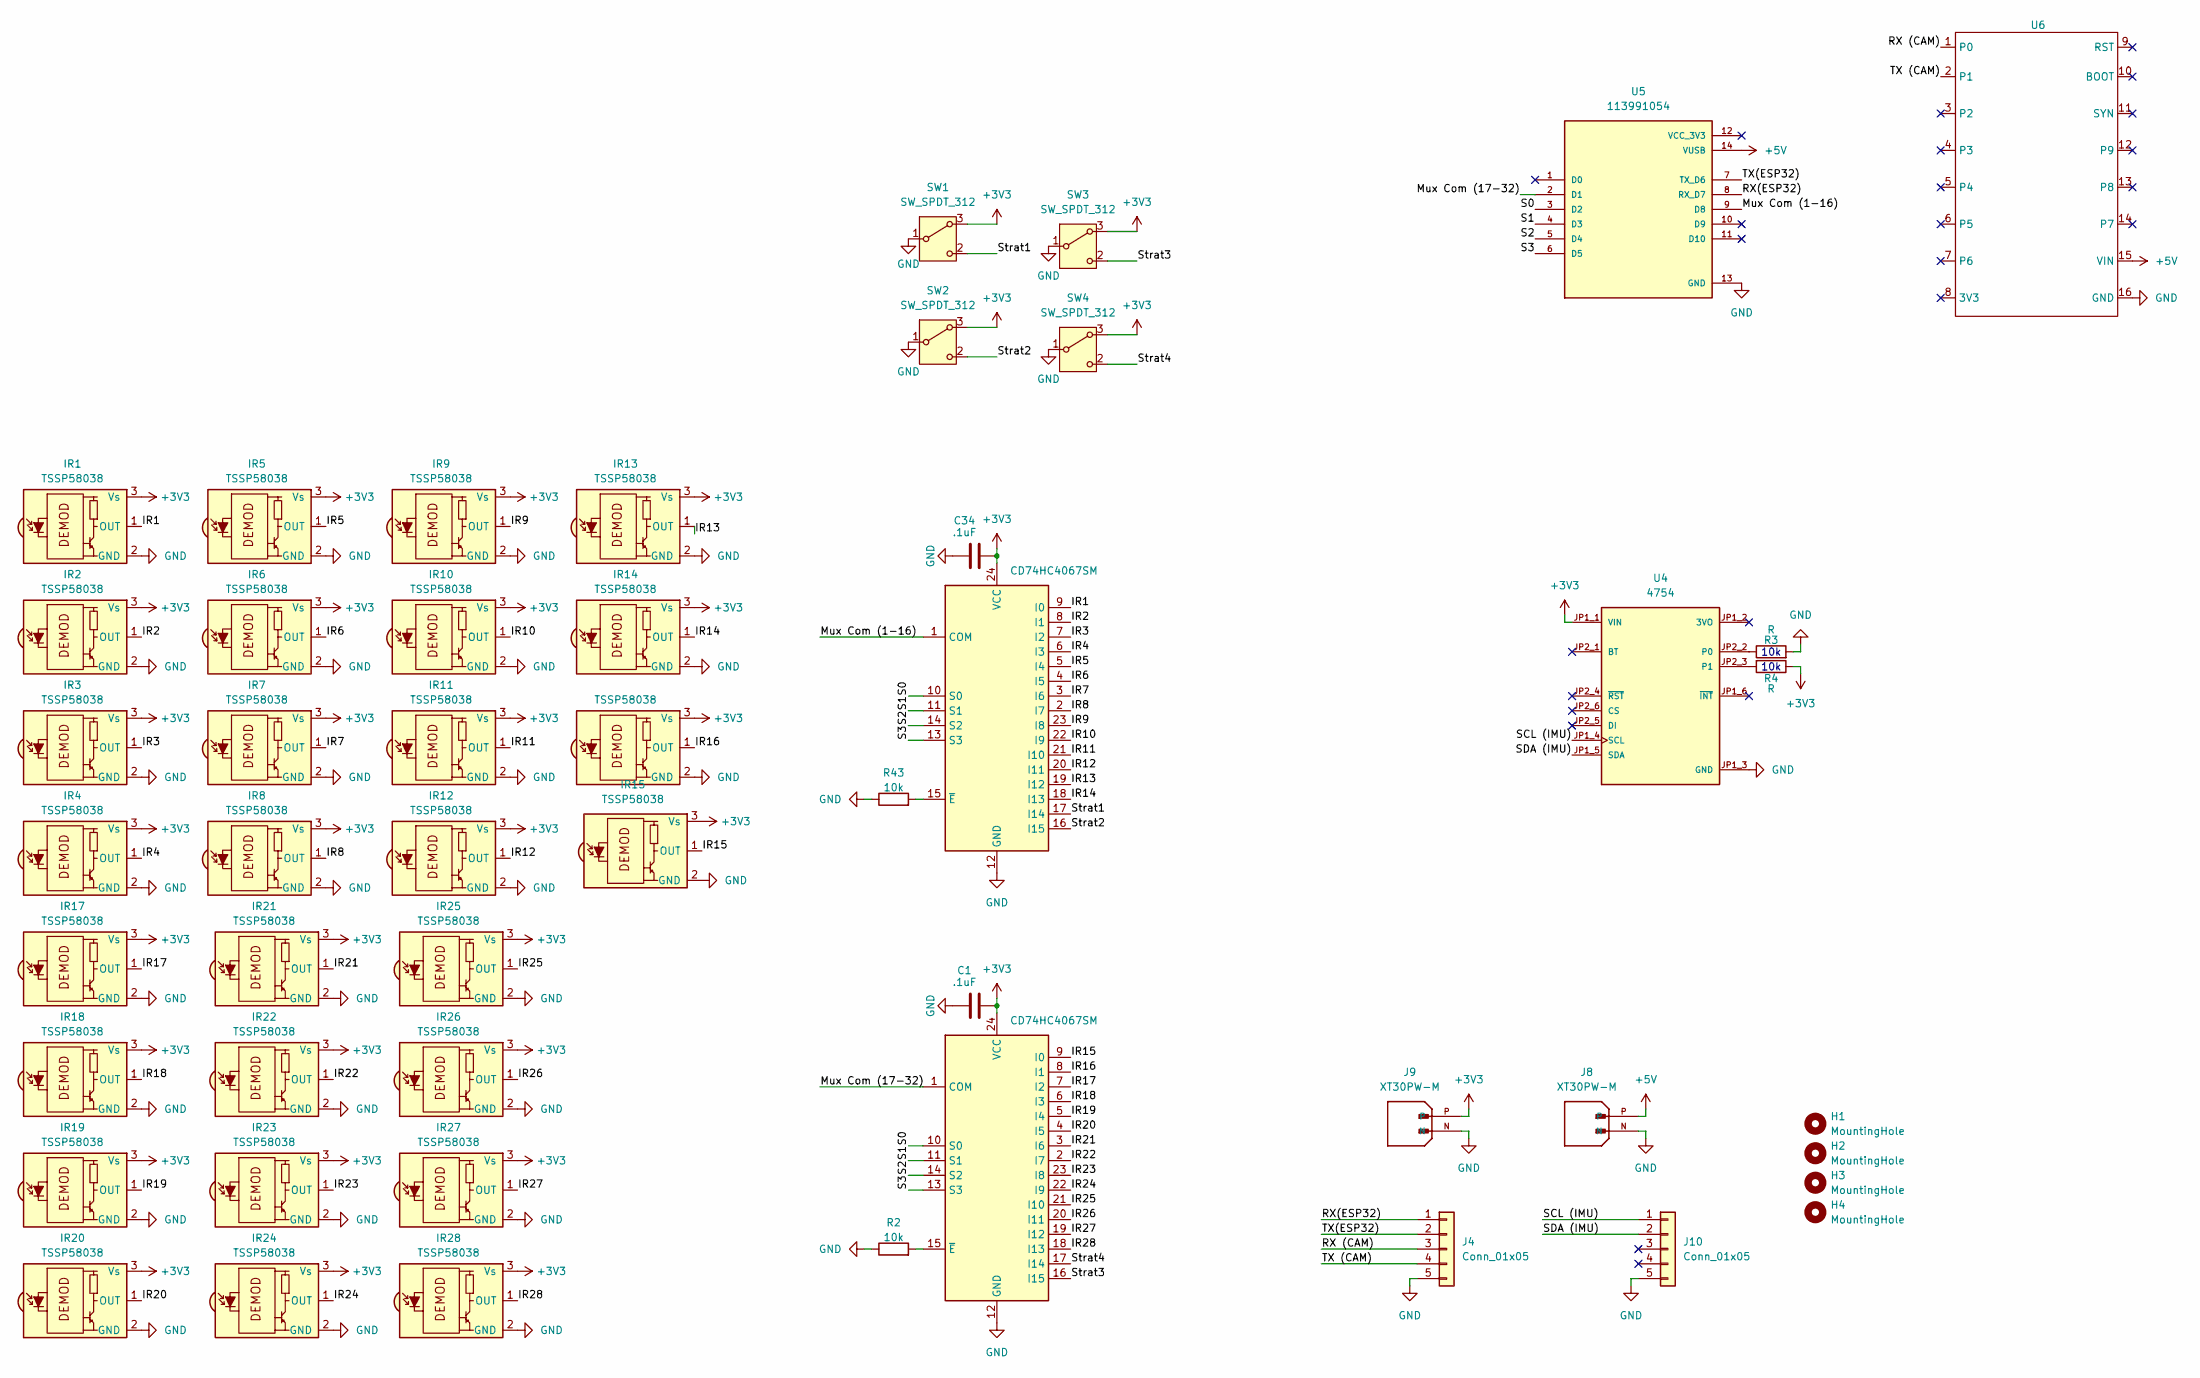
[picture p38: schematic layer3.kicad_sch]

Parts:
C1, C34: .1uF; C_0603_1608Metric
H1, H2, H3, H4: MountingHole; MountingHole_3.2mm_M3_DIN965_Pad
IR1, IR2, IR3, IR4, IR5, IR6, IR7, IR8, IR9, IR10, IR11, IR12, IR13, IR14, IR15, IR16, IR17, IR18, IR19, IR20, IR21, IR22, IR23, IR24, IR25, IR26, IR27, IR28: TSSP58038; Vishay_MINICAST-3Pin
J4, J10: Conn_01x05; JST_XH_B5B-XH-A_1x05_P2.50mm_Vertical
J8, J9: XT30PW-M; AMASS_XT30UPB-M_1x02_P5.0mm_Vertical; PARTREV 1.2
R2, R43: 10k; R_0603_1608Metric
R3, R4: R; R_0603_1608Metric_Pad0.98x0.95mm_HandSolder
SW1, SW2, SW3, SW4: SW_SPDT_312; SS12D00G3
U1, U2: CD74HC4067SM
U4: 4754; MODULE_4754; PARTREV 2021-03-16
U5: 113991054; XiaoSeeedStudioEsp32; PARTREV 23/05/2022
U6: OPENMV_M7

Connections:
+3V3: C1.2, C34.2, IR1.3 (Vs), IR2.3 (Vs), IR3.3 (Vs), IR4.3 (Vs), IR5.3 (Vs), IR6.3 (Vs), IR7.3 (Vs), IR8.3 (Vs), IR9.3 (Vs), IR10.3 (Vs), IR11.3 (Vs), IR12.3 (Vs), IR13.3 (Vs), IR14.3 (Vs), IR15.3 (Vs), IR16.3 (Vs), IR17.3 (Vs), IR18.3 (Vs), IR19.3 (Vs), IR20.3 (Vs), IR21.3 (Vs), IR22.3 (Vs), IR23.3 (Vs), IR24.3 (Vs), IR25.3 (Vs), IR26.3 (Vs), IR27.3 (Vs), IR28.3 (Vs), J9.P, R4.1, SW1.3 (A), SW2.3 (A), SW3.3 (A), SW4.3 (A), U1.24 (VCC), U2.24 (VCC), U4.JP1_1 (VIN)
+5V: J8.P, U5.14 (VUSB), U6.15 (VIN)
/IR1: IR1.1 (OUT), U2.9 (I0)
/IR2: IR2.1 (OUT), U2.8 (I1)
/IR3: IR3.1 (OUT), U2.7 (I2)
/IR4: IR4.1 (OUT), U2.6 (I3)
/IR5: IR5.1 (OUT), U2.5 (I4)
/IR6: IR6.1 (OUT), U2.4 (I5)
/IR7: IR7.1 (OUT), U2.3 (I6)
/IR8: IR8.1 (OUT), U2.2 (I7)
/IR9: IR9.1 (OUT), U2.23 (I8)
/IR10: IR10.1 (OUT), U2.22 (I9)
/IR11: IR11.1 (OUT), U2.21 (I10)
/IR12: IR12.1 (OUT), U2.20 (I11)
/IR13: IR13.1 (OUT), U2.19 (I12)
/IR14: IR14.1 (OUT), U2.18 (I13)
/IR15: IR15.1 (OUT), U1.9 (I0)
/IR16: IR16.1 (OUT), U1.8 (I1)
/IR17: IR17.1 (OUT), U1.7 (I2)
/IR18: IR18.1 (OUT), U1.6 (I3)
/IR19: IR19.1 (OUT), U1.5 (I4)
/IR20: IR20.1 (OUT), U1.4 (I5)
/IR21: IR21.1 (OUT), U1.3 (I6)
/IR22: IR22.1 (OUT), U1.2 (I7)
/IR23: IR23.1 (OUT), U1.23 (I8)
/IR24: IR24.1 (OUT), U1.22 (I9)
/IR25: IR25.1 (OUT), U1.21 (I10)
/IR26: IR26.1 (OUT), U1.20 (I11)
/IR27: IR27.1 (OUT), U1.19 (I12)
/IR28: IR28.1 (OUT), U1.18 (I13)
/Mux Com (1-16): U2.1 (COM), U5.9 (D8)
/Mux Com (17-32): U1.1 (COM), U5.2 (D1)
/RX (CAM): J4.3, U6.1 (P0)
/RX(ESP32): J4.1, U5.8 (RX_D7)
/S0: U1.10 (S0), U2.10 (S0), U5.3 (D2)
/S1: U1.11 (S1), U2.11 (S1), U5.4 (D3)
/S2: U1.14 (S2), U2.14 (S2), U5.5 (D4)
/S3: U1.13 (S3), U2.13 (S3), U5.6 (D5)
/SCL (IMU): J10.1, U4.JP1_4 (SCL)
/SDA (IMU): J10.2, U4.JP1_5 (SDA)
/Strat1: SW1.2 (C), U2.17 (I14)
/Strat2: SW2.2 (C), U2.16 (I15)
/Strat3: SW3.2 (C), U1.16 (I15)
/Strat4: SW4.2 (C), U1.17 (I14)
/TX (CAM): J4.4, U6.2 (P1)
/TX(ESP32): J4.2, U5.7 (TX_D6)
GND: C1.1, C34.1, IR1.2 (GND), IR2.2 (GND), IR3.2 (GND), IR4.2 (GND), IR5.2 (GND), IR6.2 (GND), IR7.2 (GND), IR8.2 (GND), IR9.2 (GND), IR10.2 (GND), IR11.2 (GND), IR12.2 (GND), IR13.2 (GND), IR14.2 (GND), IR15.2 (GND), IR16.2 (GND), IR17.2 (GND), IR18.2 (GND), IR19.2 (GND), IR20.2 (GND), IR21.2 (GND), IR22.2 (GND), IR23.2 (GND), IR24.2 (GND), IR25.2 (GND), IR26.2 (GND), IR27.2 (GND), IR28.2 (GND), J4.5, J8.N, J9.N, J10.5, R2.1, R3.2, R43.1, SW1.1 (B), SW2.1 (B), SW3.1 (B), SW4.1 (B), U1.12 (GND), U2.12 (GND), U4.JP1_3 (GND), U5.13 (GND), U6.16 (GND)
unnamed: R2.2, U1.15 (~E)
unnamed: R43.2, U2.15 (~E)
unnamed: R3.1, U4.JP2_2 (P0)
unnamed: R4.2, U4.JP2_3 (P1)

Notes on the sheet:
10k

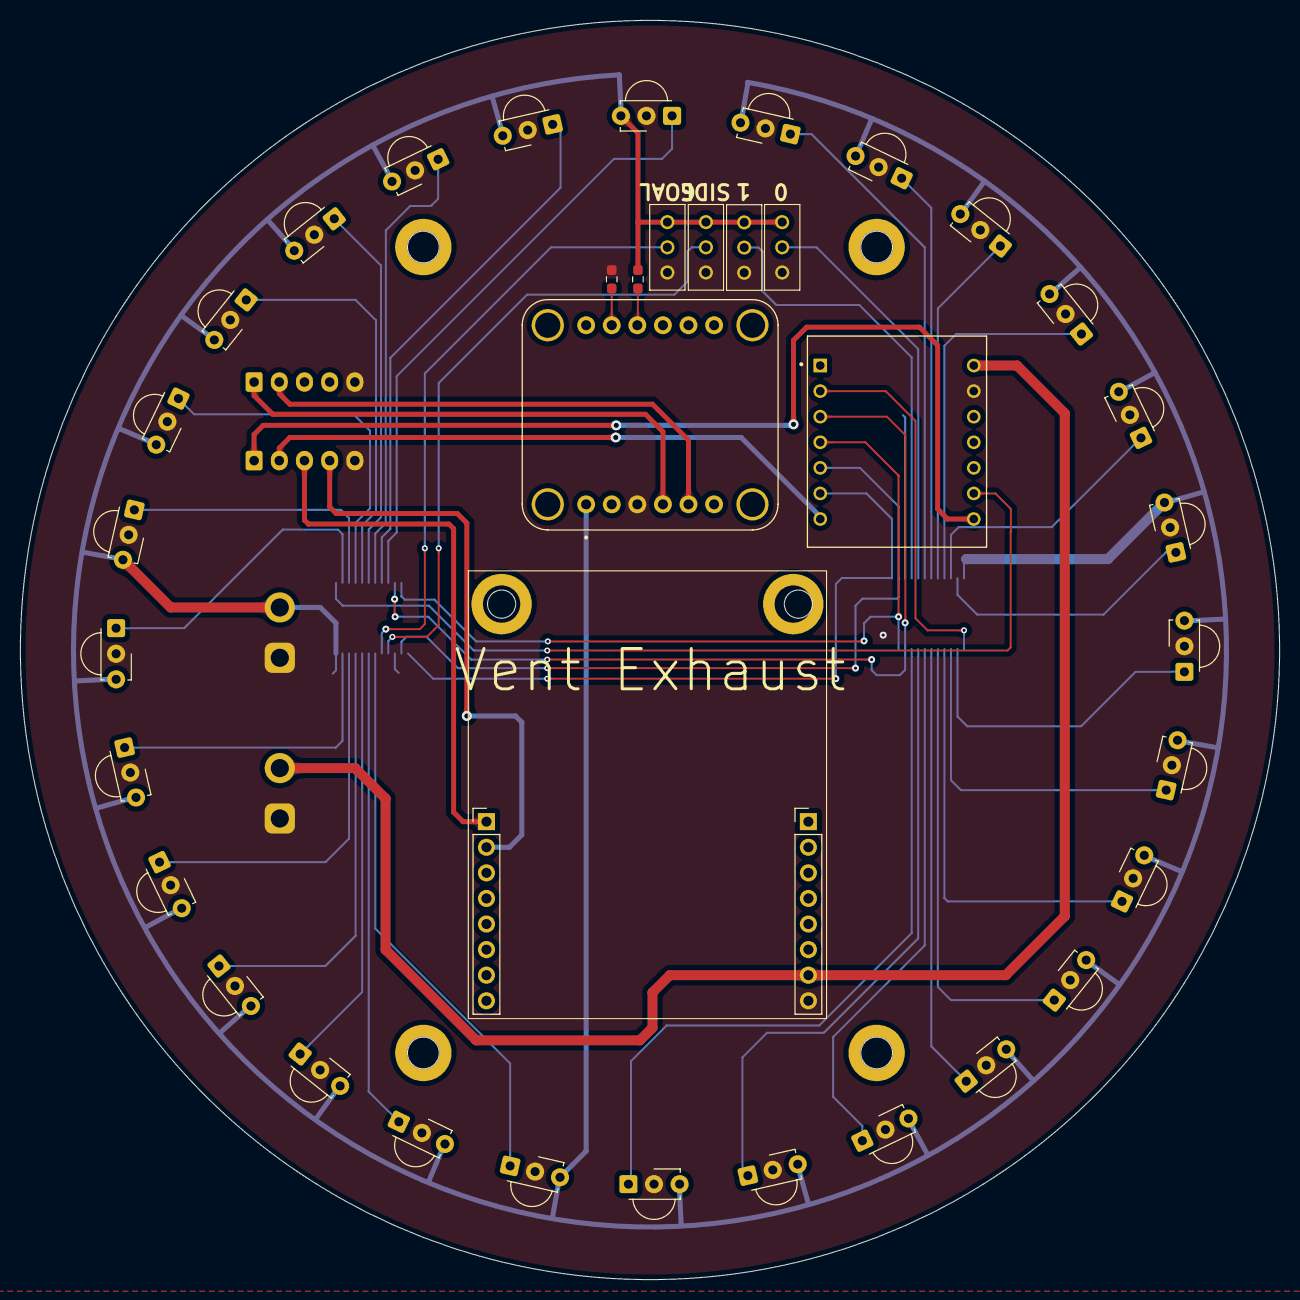
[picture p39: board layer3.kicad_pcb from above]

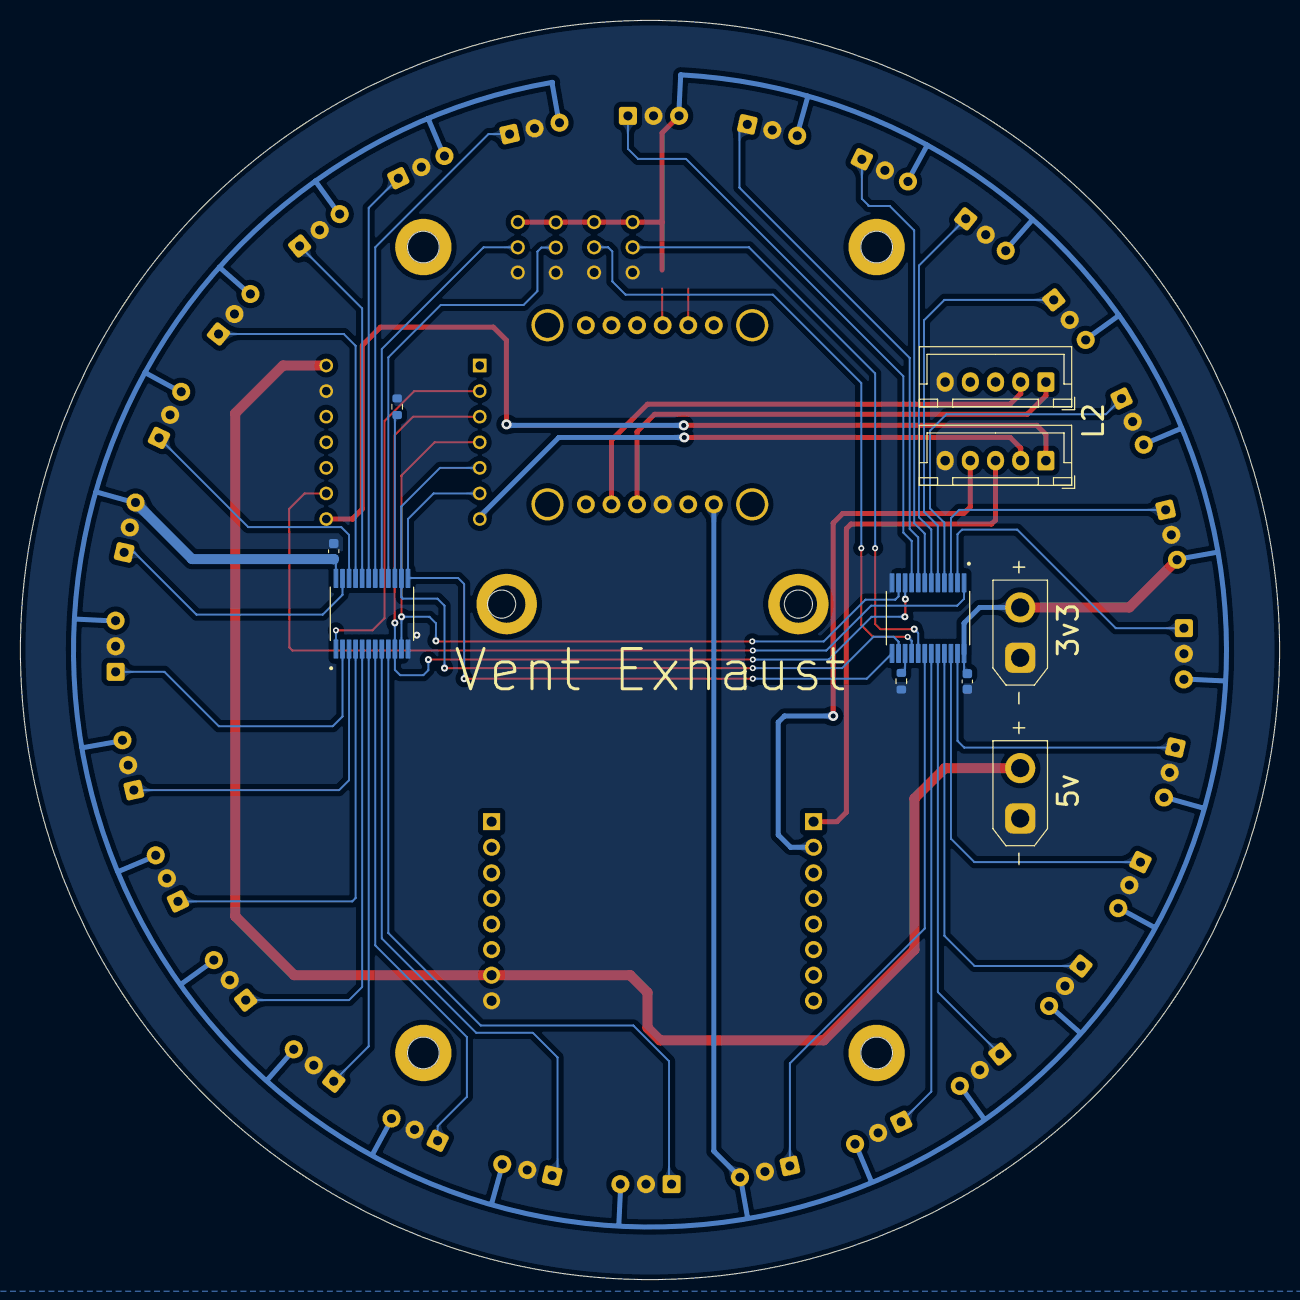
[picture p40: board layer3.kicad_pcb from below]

Board: 2 copper layers, 125.0 x 125.0 mm, 51 parts (10 on the bottom side), 51 nets.

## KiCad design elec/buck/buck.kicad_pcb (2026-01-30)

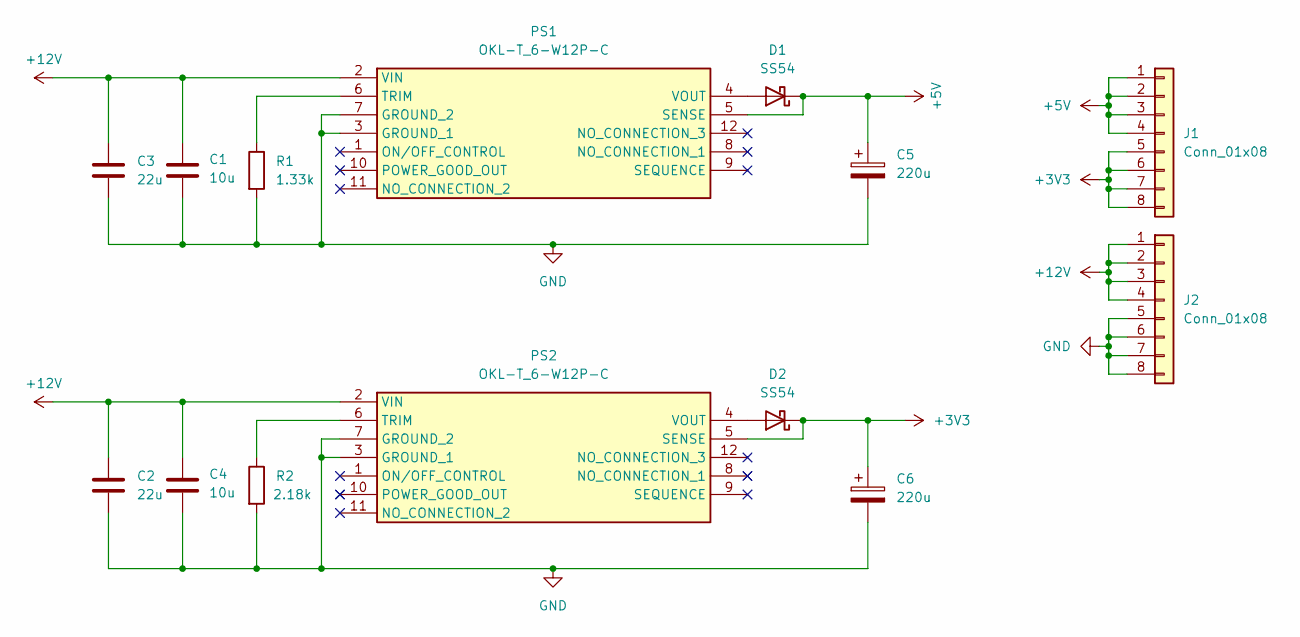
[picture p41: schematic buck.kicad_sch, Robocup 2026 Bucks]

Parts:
C1, C4: 10u; C_0603_1608Metric
C2, C3: 22u; C_0603_1608Metric
C5, C6: 220u; CP_EIA-7343-15_Kemet-W_HandSolder
D1, D2: SS54
J1, J2: Conn_01x08; PinHeader_1x08_P2.54mm_Vertical
PS1, PS2: OKL-T_6-W12P-C; MURATA_OKL-T-6-W12; Mouser Part Number 580-OKL-T/6-W12P-C
R1: 1.33k; R_0603_1608Metric
R2: 2.18k; R_0603_1608Metric

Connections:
+3V3: C6.1, D2.1 (K), J1.5, J1.6, J1.7, J1.8, PS2.5 (SENSE)
+5V: C5.1, D1.1 (K), J1.1, J1.2, J1.3, J1.4, PS1.5 (SENSE)
+12V: C1.1, C2.1, C3.1, C4.1, J2.1, J2.2, J2.3, J2.4, PS1.2 (VIN), PS2.2 (VIN)
GND: C1.2, C2.2, C3.2, C4.2, C5.2, C6.2, J2.5, J2.6, J2.7, J2.8, PS1.3 (GROUND_1), PS1.7 (GROUND_2), PS2.3 (GROUND_1), PS2.7 (GROUND_2), R1.2, R2.2
unnamed: D1.2 (A), PS1.4 (VOUT)
unnamed: D2.2 (A), PS2.4 (VOUT)
unnamed: PS1.6 (TRIM), R1.1
unnamed: PS2.6 (TRIM), R2.1

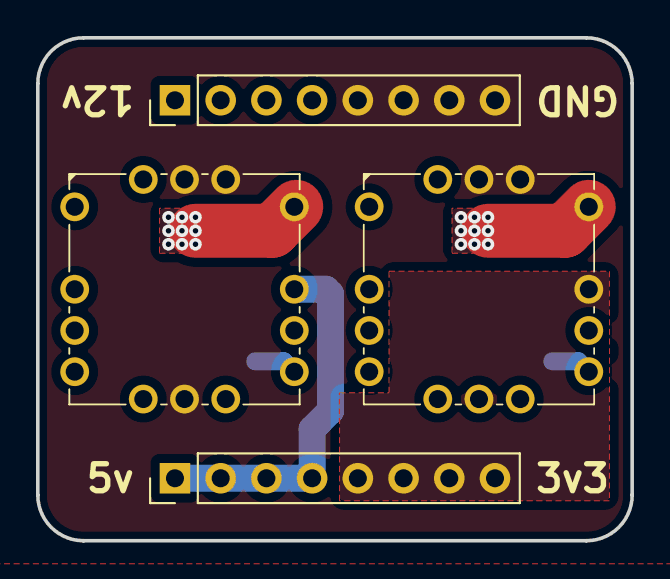
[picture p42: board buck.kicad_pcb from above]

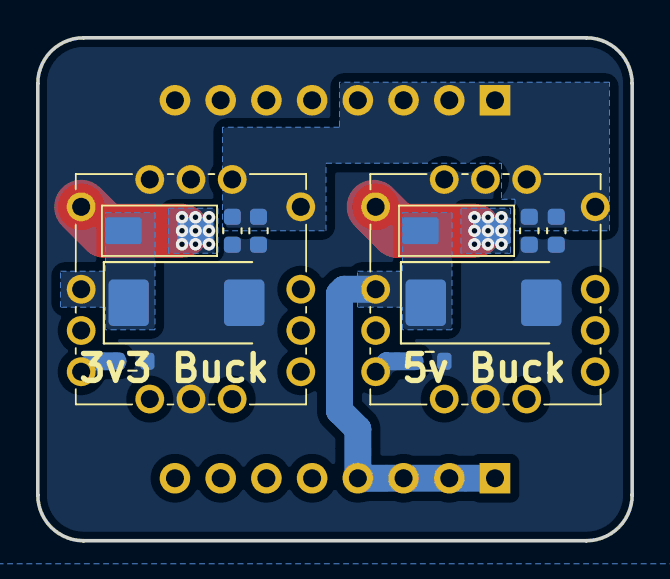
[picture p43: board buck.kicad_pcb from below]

Board: 2 copper layers, 33.0 x 27.9 mm, 14 parts (10 on the bottom side), 8 nets.

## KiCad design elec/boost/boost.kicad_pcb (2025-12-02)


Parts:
C1, C36: 100uF; CP_Radial_D8.0mm_P3.50mm; LCSC C249586
C35: 0.1uF; C_0603_1608Metric; LCSC C3011705
C40: 0.68uF; C_0603_1608Metric; LCSC C59782
D2: MBR745; TO-220-2_Vertical
J1, J2: Conn_01x08; PinHeader_1x08_P2.54mm_Vertical
L33: 33uH; L_APV_APH1040; LCSC C2875750
R36: 2K/2.94k; C_0603_1608Metric; LCSC C22843
R38: 3K; C_0603_1608Metric; LCSC C137748
U1: LM2587S-ADJ; VREG_TPS79625KTTR
VR1: TC33X-2-104E; TC33X2104E; Mouser Part Number 652-TC33X-2-104E

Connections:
+12V: C1.1, C35.1, C36.1, J1.1, J1.2, J1.3, L33.1, U1.5 (VIN)
+24V: D2.1 (K), J2.3, J2.4, J2.5, J2.6, VR1.3
GND: C1.2, C35.2, C36.2, C40.2, J1.6, J1.7, J1.8, R36.2, U1.3 (GND), U1.6 (GND)
unnamed: C40.1, R38.2
unnamed: D2.2 (A), L33.2, U1.4 (SW)
unnamed: R38.1, U1.1 (COMP)
unnamed: R36.1, U1.2 (FB), VR1.1, VR1.2


Board: 2 copper layers, 30.5 x 40.6 mm, 12 parts (0 on the bottom side), 7 nets.

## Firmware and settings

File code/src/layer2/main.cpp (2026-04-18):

#include "main.h"

// ── Localisation state ──────────────────────────────────────────────────────
static const float GOAL_SEP     = 194.0f;
static const float HALF_FIELD   = 97.0f;
static float imuOffset          = 0;
static bool  imuOffsetValid     = false;
float locX = 0, locY = 0, locHeading = 0;
bool  locValid = false;

// Return-to-centre tuning
static const float LOC_KP        = 0.003f;
static const float LOC_SPEED_MIN = 0.1f;
static const float LOC_SPEED_MAX = 0.3f;
static const float LOC_DEADZONE  = 3.0f;

// Field boundary speed cap
static const float FIELD_HALF_Y     = 109.5f;
static const float FIELD_HALF_X     = 79.0f;
static const float EDGE_MARGIN      = 20.0f;
static const float EDGE_SPEED_CAP   = 0.15f;

// ── Localisation ────────────────────────────────────────────────────────────

static void locFromOneGoal(float dist, float angle, float goalWorldY,
                           float headingDeg, float& posX, float& posY) {
    float a  = angle * DEG_TO_RAD;
    float rx = dist * sinf(a);
    float ry = dist * cosf(a);
    float th = headingDeg * DEG_TO_RAD;
    float cosT = cosf(th), sinT = sinf(th);
    posX = -(rx * cosT + ry * sinT);
    posY = goalWorldY + rx * sinT - ry * cosT;
}

static void updateLocalisation() {
    locValid = false;

    if (camBlueDetected && camYellowDetected) {
        float a1 = camBlueAngle   * DEG_TO_RAD;
        float a2 = camYellowAngle * DEG_TO_RAD;
        float bx = camBlueDist   * sinf(a1);
        float by = camBlueDist   * cosf(a1);
        float gx = camYellowDist * sinf(a2);
        float gy = camYellowDist * cosf(a2);
        float dx = gx - bx, dy = gy - by;
        float r  = sqrtf(dx * dx + dy * dy);
        if (r < 1.0f) return;

        float scale = GOAL_SEP / r;
        locHeading = atan2f(-dx, dy) * RAD_TO_DEG;
        locX = (by * gx - bx * gy) / r * scale;
        locY = (-(bx * dx + by * dy) / r - r / 2.0f) * scale;

        imuOffset = locHeading - imuYaw;
        imuOffsetValid = true;
        locValid = true;
    } else if (imuOffsetValid && (camBlueDetected || camYellowDetected)) {
        // If IMU is alive, track heading via imuYaw + offset.
        // If IMU has frozen, hold the last cam-derived locHeading instead —
        // short-term stale heading is better than a stuck imuYaw value.
        if (isImuHealthy()) {
            locHeading = imuYaw + imuOffset;
        }
        if (camBlueDetected)
            locFromOneGoal(camBlueDist, camBlueAngle, -HALF_FIELD, locHeading, locX, locY);
        else
            locFromOneGoal(camYellowDist, camYellowAngle, HALF_FIELD, locHeading, locX, locY);
        locValid = true;
    }
}

static float edgeSpeedCap(float moveAngleDeg, float headingDeg) {
    if (!locValid) return LOC_SPEED_MAX;

    float worldMoveDeg = headingDeg + moveAngleDeg;
    float worldMoveRad = worldMoveDeg * DEG_TO_RAD;
    float moveDirX = sinf(worldMoveRad);
    float moveDirY = cosf(worldMoveRad);

    float distToEdgeXp = FIELD_HALF_X - locX;
    float distToEdgeXn = FIELD_HALF_X + locX;
    float distToEdgeYp = FIELD_HALF_Y - locY;
    float distToEdgeYn = FIELD_HALF_Y + locY;

    bool nearEdge = false;
    if (distToEdgeXp < EDGE_MARGIN && moveDirX > 0) nearEdge = true;
    if (distToEdgeXn < EDGE_MARGIN && moveDirX < 0) nearEdge = true;
    if (distToEdgeYp < EDGE_MARGIN && moveDirY > 0) nearEdge = true;
    if (distToEdgeYn < EDGE_MARGIN && moveDirY < 0) nearEdge = true;

    return nearEdge ? EDGE_SPEED_CAP : LOC_SPEED_MAX;
}

// ── Striker face-goal heading correction ────────────────────────────────────

static const float FACE_KP             = 0.0008f;
static const float FACE_KD             = 0.0009f;
static const float FACE_DEADZONE_FAR   = 10.0f;
static const float FACE_DEADZONE_NEAR  = 8.0f;
static const float FACE_NEAR_DIST      = 60.0f;
static const float FACE_OMEGA_MIN      = 0.0f;
static const float FACE_OMEGA_MAX      = 0.2f;

static float prevFaceErr = 0;

static float computeFaceOmega(bool goalVis, float goalAng, float goalDst) {
    float err;
    if (goalVis) {
        err = goalAng;
    } else {
        err = -imuYaw;
    }
    if (err >  180.0f) err -= 360.0f;
    if (err < -180.0f) err += 360.0f;

    float deadzone = (goalVis && goalDst < FACE_NEAR_DIST)
                     ? FACE_DEADZONE_NEAR : FACE_DEADZONE_FAR;

    float omega = 0;
    if (fabsf(err) > deadzone) {
        float derivative = err - prevFaceErr;
        float raw = err * FACE_KP + derivative * FACE_KD;
        float sign = (raw > 0) ? 1.0f : -1.0f;
        omega = sign * constrain(fabsf(raw), FACE_OMEGA_MIN, FACE_OMEGA_MAX);
    }
    prevFaceErr = err;
    return omega;
}

// ── Line avoidance helper ──────────────────────────────────────────────────

static void applyLineAvoidance(float& moveAngle, float& speed, float& omega) {
    if (!l1LineDetected) return;
    omega = 0;
    if (locValid) {
        // Back-line override: rear LDR sensors report ~90° instead of 180°,
        // so when localisation shows we're near/behind the goalie line,
        // ignore L1 angle and drive straight forward (toward centre Y).
        #if ATTACK_GOAL == 0
        bool nearBackLine = locY > fabsf(STRIKER_BACK_LINE_Y); // defending positive Y side
        float forwardWorld = 180.0f;                          // world heading toward negative Y
        #else
        bool nearBackLine = locY < -fabsf(STRIKER_BACK_LINE_Y); // defending negative Y side
        float forwardWorld = 0.0f;                            // world heading toward positive Y
        #endif

        float escapeWorld;
        if (nearBackLine) {
            escapeWorld = forwardWorld;
            Serial.printf("[LINE] back-line override y=%.1f\n", locY);
        } else {
            escapeWorld = atan2f(-locX, -locY) * RAD_TO_DEG;
            Serial.printf("[LINE] loc x=%.1f y=%.1f\n", locX, locY);
        }

        moveAngle = escapeWorld - locHeading;
        if (moveAngle >  180.0f) moveAngle -= 360.0f;
        if (moveAngle < -180.0f) moveAngle += 360.0f;
        speed = LINE_PUSH_SPEED;
        Serial.printf("[LINE] move=%.1f\n", moveAngle);
    } else {
        float lineRad = l1Angle * DEG_TO_RAD;
        float moveRad = moveAngle * DEG_TO_RAD;
        float mvx = speed * sinf(moveRad);
        float mvy = speed * cosf(moveRad);
        float lx  = sinf(lineRad);
        float ly  = cosf(lineRad);
        float dot = mvx * lx + mvy * ly;
        if (dot > 0) { mvx -= dot * lx; mvy -= dot * ly; }
        mvx -= LINE_PUSH_SPEED * lx;
        mvy -= LINE_PUSH_SPEED * ly;
        speed = sqrtf(mvx * mvx + mvy * mvy);
        moveAngle = atan2f(mvx, mvy) * RAD_TO_DEG;
        Serial.printf("[LINE] no loc, l1 fallback angle=%.1f\n", l1Angle);
    }
}

// ── Striker ────────────────────────────────────────────────────────────────

static void strikerLoop() {
    #if ATTACK_GOAL == 0
    bool  goalVisible = camBlueDetected;
    float goalAngle   = camBlueAngle;
    float goalDist    = camBlueDist;
    #else
    bool  goalVisible = camYellowDetected;
    float goalAngle   = camYellowAngle;
    float goalDist    = camYellowDist;
    #endif

    float omega = computeFaceOmega(goalVisible, goalAngle, goalDist);

    // ── Scoring ──────────────────────────────────────────────────────
    if (checkCatchment() && goalVisible && goalDist < SCORE_DIST_THRESH) {
        kickSol();
        Serial.printf("[KICK] goalDist=%.1f\n", goalDist);
    }

    // ── IR orbit ──────────────────────────────────────────────────────
    if (l3BallDetected) {
        float ballAngle = l3BallAngle;
        if (ballAngle > 180.0f) ballAngle -= 360.0f;

        static unsigned long lastCamBallMs = 0;
        if (camBallDetected) lastCamBallMs = millis();
        bool closeEnough = (millis() - lastCamBallMs < 2000);
        float moveAngle, speed;

        if (!closeEnough) {
            moveAngle = ballAngle;
            speed = IR_CHASE_SPEED;
            Serial.printf("[IR CHASE] ball=%.1f\n", l3BallAngle);
        } else {
            float absBall = fabsf(ballAngle);
            float offsetScale = fminf(absBall / IR_ORBIT_FADE_DEG, 1.0f);
            float sign = (ballAngle > 0) ? 1.0f : -1.0f;
            moveAngle = ballAngle + sign * IR_ORBIT_OFFSET * offsetScale;
            moveAngle = constrain(moveAngle, -180.0f, 180.0f);
            speed = IR_ORBIT_SPEED_MIN
                  + (IR_ORBIT_SPEED_MAX - IR_ORBIT_SPEED_MIN) * (1.0f - offsetScale);
        }

        float capSpeed = closeEnough ? IR_ORBIT_SPEED_MAX : IR_CHASE_SPEED;
        float total = speed + fabsf(omega);
        if (total > capSpeed) {
            float scale = capSpeed / total;
            speed *= scale;
            omega *= scale;
        }

        float wrapped = fmodf(moveAngle + 360.0f, 90.0f);
        float distToDead = fabsf(wrapped - 45.0f);
        if (distToDead < XDRIVE_DEAD_NUDGE) {
            float nudge = XDRIVE_DEAD_NUDGE - distToDead;
            moveAngle += (wrapped < 45.0f) ? -nudge : nudge;
        }

        applyLineAvoidance(moveAngle, speed, omega);

        moveRobot(moveAngle, speed, omega);
        if (closeEnough)
            Serial.printf("[IR ORBIT] ball=%.1f move=%.1f spd=%.2f omega=%.2f count=%d\n",
                          l3BallAngle, moveAngle, speed, omega, l3BallCount);
    } else if (locValid) {
        float dist = sqrtf(locX * locX + locY * locY);
        if (dist > LOC_DEADZONE) {
            float towardCentreWorld = atan2f(-locX, -locY) * RAD_TO_DEG;
            float moveAngle = towardCentreWorld - locHeading;
            if (moveAngle >  180.0f) moveAngle -= 360.0f;
            if (moveAngle < -180.0f) moveAngle += 360.0f;
            float speed = constrain(dist * LOC_KP, LOC_SPEED_MIN, LOC_SPEED_MAX);
            moveRobot(moveAngle, speed, omega);
            Serial.printf("[RTC] x=%.1f y=%.1f dist=%.1f move=%.1f spd=%.2f\n",
                          locX, locY, dist, moveAngle, speed);
        } else {
            moveRobot(0, 0, omega);
            Serial.printf("[RTC] at centre, dist=%.1f\n", dist);
        }
    } else {
        moveRobot(0, 0, omega);
        Serial.printf("[IDLE] goal=%d err=%.1f omega=%.2f\n", goalVisible, prevFaceErr, omega);
    }
}

// ── Goalie ─────────────────────────────────────────────────────────────────
// Lateral-only goalie.
// Sits at fixed Y (GOALIE_LINE_Y) and strafes left/right to track the ball.
// Never moves forward toward the ball.

// Sign flip: ATTACK_GOAL==1 → defend blue (negative Y), ATTACK_GOAL==0 → defend yellow (positive Y)
#if ATTACK_GOAL == 1
static const float GK_SIGN = 1.0f;
#else
static const float GK_SIGN = -1.0f;
#endif

static float gkLastBallX = 0;  // last-seen ball side for when ball lost

// Rush-out state machine
enum GkRushState { GK_TRACK, GK_RUSH_FORWARD, GK_RUSH_RETREAT };
static GkRushState gkRushState = GK_TRACK;
static unsigned long gkHoldStartMs = 0;  // 0 = not currently holding in deadzone
static unsigned long gkRushStartMs = 0;
static unsigned long gkRushDurationMs = 0;  // how long the most recent rush actually lasted
static float gkRushMoveAngle = 0;        // robot-local move angle captured during rush

static void goalieLoop() {
    // Rate-limited per-loop debug (every 200ms)
    static unsigned long lastDbgMs = 0;
    bool dbg = (millis() - lastDbgMs >= 200);
    if (dbg) {
        lastDbgMs = millis();
        Serial.printf("[GK DBG] loc=%d bd=%d bang=%.1f hold=%lu state=%d locX=%.1f locY=%.1f\n",
                      locValid, l3BallDetected, l3BallAngle,
                      gkHoldStartMs ? (millis() - gkHoldStartMs) : 0UL,
                      (int)gkRushState, locX, locY);
    }

    if (!locValid) {
        moveRobot(0, 0, 0);
        Serial.println("[GK] no loc, holding");
        gkHoldStartMs = 0;
        gkRushState = GK_TRACK;
        return;
    }

    // ── Rush forward: drive toward the ball while it stays in the cone ─
    if (gkRushState == GK_RUSH_FORWARD) {
        unsigned long elapsed = millis() - gkRushStartMs;

        auto beginRetreat = [&](const char* reason) {
            gkRushDurationMs = elapsed;
            gkRushState = GK_RUSH_RETREAT;
            gkRushStartMs = millis();
            moveRobot(0, 0, 0);
            Serial.printf("[GK RUSH] → retreat (%s) duration=%lu\n", reason, gkRushDurationMs);
        };

        // Exit if duration cap hit
        if (elapsed >= GOALIE_RUSH_DURATION_MS) {
            beginRetreat("timeout");
            return;
        }
        // Exit if ball lost or angle leaves the deadzone cone
        bool stillInCone = false;
        float ballAng = 0;
        if (l3BallDetected) {
            ballAng = l3BallAngle;
            if (ballAng > 180.0f) ballAng -= 360.0f;
            stillInCone = (fabsf(ballAng) < GOALIE_RUSH_DEADZONE_DEG);
        }
        if (!stillInCone) {
            beginRetreat(l3BallDetected ? "out-of-cone" : "no-ball");
            return;
        }
        // Kick if ball enters catchment, then retreat (only after min drive time)
        if (elapsed >= GOALIE_RUSH_MIN_DRIVE_MS && checkCatchment()) {
            kickSol();
            Serial.printf("[GK RUSH] kick\n");
            beginRetreat("kick");
            return;
        }
        gkRushMoveAngle = ballAng;
        float preSpeed = GOALIE_RUSH_SPEED;
        float preAngle = gkRushMoveAngle;
        float speed = preSpeed;
        float omega = 0;
        float moveAngle = preAngle;
        applyLineAvoidance(moveAngle, speed, omega);
        moveRobot(moveAngle, speed, omega);
        if (dbg) Serial.printf("[GK RUSH] fwd t=%lu bang=%.1f pre(%.1f,%.2f) post(%.1f,%.2f) line=%d\n",
                               elapsed, ballAng, preAngle, preSpeed,
                               moveAngle, speed, l1LineDetected);
        return;
    }

    // ── Retreat: drive opposite to rush direction for the same duration ─
    if (gkRushState == GK_RUSH_RETREAT) {
        unsigned long elapsed = millis() - gkRushStartMs;
        if (elapsed >= gkRushDurationMs + GOALIE_RETREAT_EXTRA_MS) {
            Serial.printf("[GK RUSH] retreat done elapsed=%lu\n", elapsed);
            gkRushState = GK_TRACK;
            gkHoldStartMs = 0;
            // Fall through to normal tracking
        } else {
            float moveAngle = gkRushMoveAngle + 180.0f;
            if (moveAngle >  180.0f) moveAngle -= 360.0f;
            if (moveAngle < -180.0f) moveAngle += 360.0f;
            float speed = GOALIE_RETREAT_SPEED;
            float omega = 0;
            applyLineAvoidance(moveAngle, speed, omega);
            moveRobot(moveAngle, speed, omega);
            if (dbg) Serial.printf("[GK RUSH] retreat t=%lu/%lu move=%.1f spd=%.2f\n",
                                   elapsed, gkRushDurationMs, moveAngle, speed);
            return;
        }
    }

    // ── Rush trigger: ball sitting in front of robot for too long ─────
    // Uses a grace period so brief IR dropouts or single-frame cone
    // exits don't zero the hold timer.
    static unsigned long gkLastInConeMs = 0;
    const unsigned long GK_HOLD_GRACE_MS = 400;

    bool ballInCone = false;
    float ballAngDbg = 0;
    if (l3BallDetected) {
        ballAngDbg = l3BallAngle;
        if (ballAngDbg > 180.0f) ballAngDbg -= 360.0f;
        ballInCone = (fabsf(ballAngDbg) < GOALIE_RUSH_DEADZONE_DEG);
    }
    if (ballInCone) {
        gkLastInConeMs = millis();
        if (gkHoldStartMs == 0) gkHoldStartMs = millis();
    } else if (gkLastInConeMs != 0 &&
               millis() - gkLastInConeMs > GK_HOLD_GRACE_MS) {
        // Ball has been out of cone long enough → reset
        gkHoldStartMs = 0;
        gkLastInConeMs = 0;
    }
    if (gkHoldStartMs != 0) {
        unsigned long heldFor = millis() - gkHoldStartMs;
        if (heldFor >= GOALIE_STUCK_TIMEOUT_MS) {
            gkRushState = GK_RUSH_FORWARD;
            gkRushStartMs = millis();
            gkHoldStartMs = 0;
            gkLastInConeMs = 0;
            Serial.printf("[GK] ball in front %lums → RUSH\n", heldFor);
            moveRobot(0, 0, 0);
            return;
        }
    }

    // Fixed Y position in front of own goal
    float lineY = GK_SIGN * GOALIE_LINE_Y;

    // 1. Determine target X from IR ball angle
    float tgtX = 0;
    if (l3BallDetected) {
        float ballAng = l3BallAngle;
        if (ballAng > 180.0f) ballAng -= 360.0f;
        tgtX = GK_SIGN * GOALIE_BALL_X_SCALE * sinf(ballAng * DEG_TO_RAD);
        gkLastBallX = tgtX;
    } else {
        // No ball: return to middle of goal line
        tgtX = 0;
    }
    tgtX = constrain(tgtX, -GOALIE_X_MAX, GOALIE_X_MAX);

    // 2. Compute world-frame errors
    float errX = tgtX  - locX;
    float errY = lineY - locY;

    // 3. Zero out whichever axis is inside its dead zone
    if (fabsf(errX) < GOALIE_DEADZONE_X) errX = 0;
    if (fabsf(errY) < GOALIE_DEADZONE_Y) errY = 0;

    if (errX == 0 && errY == 0) {
        moveRobot(0, 0, 0);
        if (dbg) Serial.printf("[GK] holding x=%.0f y=%.0f\n", locX, locY);
        return;
    }

    // 4. Per-axis P → world velocity vector
    float vx = GOALIE_LATERAL_KP      * errX;
    float vy = GOALIE_LONGITUDINAL_KP * errY;

    float speed = sqrtf(vx*vx + vy*vy);
    speed = constrain(speed, GOALIE_SPEED_MIN, GOALIE_SPEED_MAX);
    if (!l3BallDetected) speed = constrain(speed, 0.10f, 0.20f);

    // 5. Convert world vector → robot-local move angle
    //    moveRobot angle: 0°=forward(+Y world if heading=0), 90°=right(+X)
    float worldAng = atan2f(vx, vy) * RAD_TO_DEG;
    float moveAngle = worldAng - locHeading;
    while (moveAngle >  180.0f) moveAngle -= 360.0f;
    while (moveAngle < -180.0f) moveAngle += 360.0f;

    float omega = 0;
    applyLineAvoidance(moveAngle, speed, omega);

    moveRobot(moveAngle, speed, omega);
    if (dbg) Serial.printf("[GK] x=%.0f y=%.0f tgtX=%.0f lineY=%.0f errX=%.0f errY=%.0f spd=%.2f\n",
                           locX, locY, tgtX, lineY, errX, errY, speed);
}

// ── Main ────────────────────────────────────────────────────────────────────

void setup() {
    setupESC();
    Serial.begin(115200);
    setupL1Comm();
    setupCamComm();
    setupL3Comm();

    setupMotors();
    setupSol();
    setupLightgate();
    setupIMU();

    delay(500);
    resetYawTarget();
}

void loop() {
    // ── Read sensors ────────────────────────────────────────────────────
    readL1();
    readL3();
    readCam();
    readIMU();

    static unsigned long lastImuPrintMs = 0;
    if (millis() - lastImuPrintMs >= 100) {
        lastImuPrintMs = millis();
        Serial.printf("[IMU] yaw=%.1f healthy=%d\n", imuYaw, isImuHealthy());
    }

    updateLocalisation();
    setCamHeading(locHeading, locValid);

    static unsigned long lastLocPrintMs = 0;
    if (millis() - lastLocPrintMs >= 200) {
        lastLocPrintMs = millis();
        Serial.printf("[LOC] valid=%d x=%.1f y=%.1f hdg=%.1f\n",
                      locValid, locX, locY, locHeading);
    }

    #if ROLE == 0
    strikerLoop();
    #else
    goalieLoop();
    #endif

    // moveRobot(0, 0.2, -0.2);
}

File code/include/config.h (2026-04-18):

#ifndef CONFIG_H
#define CONFIG_H

// =============================================================================
// BOT SELECTION — change to 1 or 2 before uploading
// =============================================================================
#define BOT 2

// =============================================================================
// LOCATION SELECTION — change per venue (affects min speeds, thresholds, etc.)
// 1 = Home    2 = Competition
// =============================================================================
#define LOCATION 2

// --- Strategy ---
// Which goal to attack: 0 = blue, 1 = yellow
#define ATTACK_GOAL 0



// Robot role: 0 = striker, 1 = goalie
#define ROLE 0

// =============================================================================
// COMPETITION TUNING — edit these values on game day
// =============================================================================

// --- Light Ring ---
// Per-sensor thresholds (0–4095). Run calibrateLightRing() to generate these.
#if BOT == 1
// constexpr int LDR_THRESHOLDS[32] = {3415, 3409, 3393, 3384, 3372, 3365, 3326, 3339, 3323, 3311, 3303, 3307, 3294, 3284, 3276, 3277, 3272, 3254, 3251, 3258, 3243, 3242, 3235, 3240, 3236, 3222, 3217, 3227, 3220, 3227, 3217, 3230};
// constexpr int LDR_THRESHOLDS[32] = {3418, 3411, 3396, 3390, 3376, 3370, 3333, 3346, 3332, 3319, 3307, 3308, 3300, 3294, 3284, 3284, 3281, 3264, 3257, 3259, 3077, 3244, 3240, 3241, 3238, 3228, 3212, 3212, 3217, 3234, 3225, 3236};
constexpr int LDR_THRESHOLDS[32] = {3387, 3390, 3374, 3366, 3347, 3342, 3299, 3318, 3302, 3288, 3276, 3286, 3271, 3270, 3253, 3248, 3256, 3230, 3221, 3239, 3078, 3214, 3212, 3220, 3215, 3198, 3203, 3203, 3198, 3207, 3196, 3212};
#elif BOT == 2
// constexpr int LDR_THRESHOLDS[32] = {3403, 3370, 3346, 3357, 3365, 3340, 3351, 3325, 3313, 3293, 3308, 3299, 3278, 3280, 3273, 3271, 3262, 3255, 3250, 3221, 3249, 3241, 3204, 3227, 3233, 3229, 3225, 3211, 3209, 3196, 3201, 3219};
constexpr int LDR_THRESHOLDS[32] = {3393, 3366, 3357, 3342, 3352, 3325, 3325, 3303, 3298, 3270, 3289, 3288, 3271, 3267, 3261, 3256, 3245, 3238, 3233, 3203, 3234, 3214, 3165, 3210, 3217, 3209, 3215, 3188, 3191, 3167, 3176, 3204};
#endif

// Samples to average per sensor reading
constexpr int LDR_SAMPLES = 25;

// Microseconds to wait after switching mux channel before reading
constexpr int MUX_SETTLE_US = 50;

// --- Calibration ---
// How many checkLightRing() calls to make per Enter press
constexpr int CALIBRATION_READS_PER_SAMPLE = 50;

// --- Main Loop ---
// Polling period in milliseconds
constexpr int LOOP_DELAY_MS = 30;

// --- Layer 2: Motor Trim ---
// Per-motor speed multipliers (0.0–1.0). Reduce a motor's value if it spins
// faster than the others. The slowest motor should stay at 1.0.
#if BOT == 1
constexpr double FR_TRIM = 1.0;  // M1
constexpr double BR_TRIM = 1.0;  // M2
constexpr double BL_TRIM = 1.0;  // M3
constexpr double FL_TRIM = 1.0;  // M4
#elif BOT == 2
constexpr double FR_TRIM = 1.0;  // M1
constexpr double BR_TRIM = 1.0;  // M2
constexpr double BL_TRIM = -1.0;  // M3
constexpr double FL_TRIM = 1.0;  // M4
#endif

// --- Layer 2: IMU Correction ---
// Yaw heading-hold PID (output added to omega)
#if BOT == 1
constexpr double YAW_KP             = 0.0003;
constexpr double YAW_KI             = 0.0;
constexpr double YAW_KD             = 0.002;
constexpr double YAW_I_MAX          = 0.35;    // integral windup limit
constexpr double YAW_CORRECTION_MAX = 0.25;     // max omega correction (0–1 scale)
#elif BOT == 2
constexpr double YAW_KP             = 0.004;
constexpr double YAW_KI             = 0.0;
constexpr double YAW_KD             = 0.004;
constexpr double YAW_I_MAX          = 0.35;
constexpr double YAW_CORRECTION_MAX = 0.4;
#endif

// Accel drift correction — P only (output added to vx/vy)
constexpr double ACCEL_KP             = 0.005;
constexpr double ACCEL_CORRECTION_MAX = 0.2;

// --- IMU Health ---
// If no new IMU reading arrives within this period, consider it disconnected
constexpr unsigned long IMU_TIMEOUT_MS = 200;
// How long to wait after reinit before resuming movement
constexpr unsigned long IMU_REINIT_SETTLE_MS = 500;

// --- Motor Smoothing ---
// EMA alpha for motor power (0.0 = frozen, 1.0 = no smoothing)
// Lower = smoother but more sluggish. 0.15–0.3 is a good range.
constexpr double MOTOR_SMOOTH_ALPHA = 0.3;

// --- Dribbler Speed ---
constexpr int DRIBBLER_SPEED = 20;

// --- Location Speed Multiplier ---
// Percentage increase applied to all min speeds (0 = no change, 50 = 50% faster)
#if LOCATION == 1
constexpr float LOCATION_SPEED_PCT = 0.0f;
#elif LOCATION == 2
constexpr float LOCATION_SPEED_PCT = -10.0f;
#endif
constexpr float LOCATION_SPEED_MULT = 1.0f + LOCATION_SPEED_PCT / 100.0f;
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

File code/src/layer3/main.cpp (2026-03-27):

// #include "main.h"

// static uint8_t myMac[6];
// static uint8_t peerMac[6];

// static uint32_t txCount    = 0;
// static uint32_t rxCount    = 0;
// static uint32_t lastTxMs   = 0;
// static uint32_t lastPrintMs = 0;
// static const char *myRole  = nullptr;

// // ── Callbacks run on the WiFi task (core 0) — independent of loop() ───────

// void onSent(const uint8_t *mac, esp_now_send_status_t status) {
//     Serial.printf("[TX] id=%-4lu  %s\n", txCount,
//                   status == ESP_NOW_SEND_SUCCESS ? "OK" : "FAIL");
// }

// void onRecv(const uint8_t *mac, const uint8_t *data, int len) {
//     if (len < (int)sizeof(Packet)) return;
//     Packet pkt;
//     memcpy(&pkt, data, sizeof(pkt));
//     rxCount++;
//     uint32_t latency = millis() - pkt.timestamp_ms;
//     Serial.printf("[RX] id=%-4lu  latency=%lums  total_rx=%lu\n",
//                   pkt.id, latency, rxCount);
// }

// // ─────────────────────────────────────────────────────────────────────────

// void setup() {
//     Serial.begin(115200);
//     delay(500);

//     WiFi.mode(WIFI_STA);
//     WiFi.macAddress(myMac);

//     Serial.printf("\nMAC: %02X:%02X:%02X:%02X:%02X:%02X\n",
//                   myMac[0], myMac[1], myMac[2],
//                   myMac[3], myMac[4], myMac[5]);

//     if (memcmp(myMac, PEER_A_MAC, 6) == 0) {
//         memcpy(peerMac, PEER_B_MAC, 6);
//         myRole = "PEER A";
//         Serial.println("Role: PEER A");
//     } else if (memcmp(myMac, PEER_B_MAC, 6) == 0) {
//         memcpy(peerMac, PEER_A_MAC, 6);
//         myRole = "PEER B";
//         Serial.println("Role: PEER B");
//     } else {
//         Serial.println("WARNING: MAC not recognised — fill in PEER_A/B_MAC in main.h");
//         while (true) {
//             Serial.printf("MY MAC: %02X:%02X:%02X:%02X:%02X:%02X\n",
//                           myMac[0], myMac[1], myMac[2],
//                           myMac[3], myMac[4], myMac[5]);
//             delay(1000);
//         }
//     }

//     if (esp_now_init() != ESP_OK) {
//         Serial.println("ESP-NOW init failed");
//         while (true) delay(1000);
//     }

//     esp_now_register_send_cb(onSent);
//     esp_now_register_recv_cb(onRecv);

//     esp_now_peer_info_t peer = {};
//     memcpy(peer.peer_addr, peerMac, 6);
//     peer.channel = 0;
//     peer.encrypt = false;
//     if (esp_now_add_peer(&peer) != ESP_OK) {
//         Serial.println("Add peer failed");
//         while (true) delay(1000);
//     }

//     Serial.println("ESP-NOW ready.\n");
// }

// void loop() {
//     uint32_t now = millis();

//     // Non-blocking TX — fires every TX_INTERVAL_MS
//     // RX always works regardless, since onRecv() runs on a separate task
//     if (now - lastTxMs >= TX_INTERVAL_MS) {
//         lastTxMs = now;
//         Packet pkt = {++txCount, now};
//         esp_now_send(peerMac, (uint8_t *)&pkt, sizeof(pkt));
//     }

//     if (now - lastPrintMs >= 1000) {
//         lastPrintMs = now;
//         Serial.printf("I am %s  |  time=%lums\n", myRole, now);
//     }

//     // ── Simulate 1-2s blocking work ───────────────────────────────────────
//     delay(2000);
//     //
//     // RX callbacks still fire during this block (WiFi task, core 0).
//     // TX will resume after the block; millis() timer catches up correctly.
//     // ─────────────────────────────────────────────────────────────────────
// }

#include "main.h"

static SerialComm l3Comm(L3_TO_L2_SERIAL);

void setupL3Comm() {
    L3_TO_L2_SERIAL.begin(115200, SERIAL_8N1, RX_L2, TX_L2);
}

void sendL3Data(BallData &ball) {
    int16_t tx[7] = {
        (int16_t)ball.detected,
        (int16_t)(ball.angle * 10),
        (int16_t)ball.activeCount,
        (int16_t)switchGoal,
        (int16_t)switchRole,
        (int16_t)switchStrat0,
        (int16_t)switchStrat1
    };
    l3Comm.write(tx, 7);
}

void selectMuxChannel(int n) {
    int binaryNum[4] = {0, 0, 0, 0};
    int tempN = n;
    int i = 0;

    while (tempN > 0 && i < 4) {
        binaryNum[i] = tempN % 2;
        tempN = tempN / 2;
        i++;
    }

    // S0 = LSB, S3 = MSB
    digitalWrite(S0, binaryNum[0]);
    digitalWrite(S1, binaryNum[1]);
    digitalWrite(S2, binaryNum[2]);
    digitalWrite(S3, binaryNum[3]);
}

bool readIR(int pin) {
    int lowCount = 0;
    for (int i = 0; i < IR_SAMPLES; i++) {
        if (digitalRead(pin) == LOW) {
            lowCount++;
        }
        delayMicroseconds(2);
    }
    return lowCount > IR_THRESHOLD;
}

void readIRs() {
    for (int i = 0; i < 14; i++) {
        selectMuxChannel(i);
        IR[i] = readIR(MUX_1);
        IR[i+14] = readIR(MUX_2);
    }
}

BallData calculateBall() {
    // Find the largest consecutive cluster of active sensors (wrapping around)
    int bestStart = -1, bestLen = 0;
    int curStart = -1, curLen = 0;

    // Double the loop to handle wraparound clusters
    for (int i = 0; i < IR_COUNT * 2; i++) {
        if (IR[i % IR_COUNT]) {
            if (curLen == 0) curStart = i;
            curLen++;
            if (curLen > bestLen) {
                bestLen = curLen;
                bestStart = curStart;
            }
        } else {
            curLen = 0;
        }
    }
    // Cap length to IR_COUNT (all sensors active edge case)
    if (bestLen > IR_COUNT) bestLen = IR_COUNT;

    // Trim noisy edge sensors if cluster is large enough, otherwise use all
    int useStart = bestStart;
    int useLen = bestLen;
    if (bestLen > 2 * IR_TRIM) {
        useStart = bestStart + IR_TRIM;
        useLen = bestLen - 2 * IR_TRIM;
    }

    BallData ball;
    ball.activeCount = bestLen;
    ball.detected = bestLen > 0;

    if (ball.detected) {
        float sumX = 0, sumY = 0;
        for (int j = 0; j < useLen; j++) {
            int idx = (useStart + j) % IR_COUNT;
            float angleDeg = fmod(270.0f - idx * (360.0f / IR_COUNT) + 360.0f, 360.0f);
            float angleRad = angleDeg * DEG_TO_RAD;
            sumX += sinf(angleRad);
            sumY += cosf(angleRad);
        }
        float angleRad = atan2f(sumX, sumY);
        ball.angle = angleRad * RAD_TO_DEG;
        if (ball.angle < 0) ball.angle += 360.0f;
    } else {
        ball.angle = 0;
    }

    return ball;
}

void debugIR() {
    for (int ir : IR) {
        Serial.print(ir);
        Serial.print(" ");
    }
    Serial.println();
}

void debugBall(BallData &ball) {
    if (ball.detected) {
        Serial.printf("[BALL] angle=%.1f  sensors=%d\n",
                      ball.angle, ball.activeCount);
    } else {
        Serial.println("[BALL] not detected");
    }
}

void readSwitches() {
    selectMuxChannel(14);
    switchGoal   = digitalRead(MUX_1);
    switchStrat0 = digitalRead(MUX_2);

    selectMuxChannel(15);
    switchRole   = digitalRead(MUX_1);
    switchStrat1 = digitalRead(MUX_2);
}
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

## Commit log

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2025-10-14 did boost without caps for now might have to re config stitch vias pos
    [boost caps.kicad_pcb, boost caps.kicad_sch, boost.kicad_pcb]
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2025-10-14 did motor driver example
    [motordrivers.kicad_pcb, motordrivers.kicad_sch]
2025-10-21 i think thats drivers done
    [motordrivers.kicad_pcb, motordrivers.kicad_sch]
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2025-10-21 sleepy but did most pcbs
    [boost caps.kicad_pcb, boost caps.kicad_sch, boost.kicad_pcb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]
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2025-10-22 added fusion fat module
    [Modules FAT.dxf, buck.kicad_pcb, layer2.kicad_pcb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]
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2025-11-02 fix: edited buck
    moved a singular tantulum by a few mm
    [buck.kicad_pcb]
2025-11-02 did buck +3d models_ the actual buck er 3d mode'
    [AON6354.STEP, L_APV_APH1040.step, SS54-HF.STEP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]
2025-11-02 added TPS5430DDAG4 3d models
    [TPS5430DDAG4.stp, buck.kicad_pcb]
2025-11-03 finishe dcaps for boost
    [boost caps.kicad_pcb, boost caps.kicad_sch, modules Caps.dxf]
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2025-11-03 finished pcbs-silkscrfeen pcbs seem halal
    [boost.kicad_pcb, solactivation.kicad_pcb, solactivation.kicad_sch]
2025-11-03 added teardrops and sus via
    [boost.kicad_pcb, buck.kicad_pcb, solactivation.kicad_pcb]
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2025-11-05 did pcba for bucks
    [buck.kicad_pcb, solactivation.kicad_pcb]
2025-11-05 did pcba for buck and boos5t
    [boost.kicad_pcb, buck.kicad_pcb]
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2025-11-30 feat: added pot to boost
    [boost.kicad_pcb, boost.kicad_sch]
2025-11-30 added 3d model for boost + PCBA
    [BOM-boost.csv, LM2587S-ADJ.stp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]
2025-11-30 Finished slaving avay buck done +PCBA
    [BOM-buck.csv, EDI2CAP.CFG, OKL-T_6-W12P-C.SchLib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]
2025-11-30 added v1 to bucks
    [buck.kicad_pcb]
2025-11-30 added name cos why not
    [boost caps.kicad_pcb, boost.kicad_pcb, buck.kicad_pcb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]
2025-12-02 chore: production files; chore: rev num for solactivation
    [BOM-solactivation.csv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]
2025-12-02 chore: boost production files
    [BOM-boost.csv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]
2025-12-02 chore: buck production files
    [buck-CuBottom.gbr, buck-CuTop.gbr, buck-EdgeCuts.gbr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]
2025-12-02 chore: boostcaps production files
    [BOM-boost caps.csv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]
2025-12-02 fix: boostcaps revision number; chore: boostcaps production files
    [boost caps-CuBottom.gbr, boost caps-CuTop.gbr, boost caps-EdgeCuts.gbr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]
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2025-12-10 feat: cone mirror files
    [cone.scad, cone.stl, cone_profile.csv]
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2026-01-02 Revert "Merge branch 'main' of https://github.com/2-chairs/robocup2026-i2"
    This reverts commit a28d608313404cc618c1ce11ffefa503b88e08b3, reversing
    changes made to 7cc45da3019f5272dff102d14f68ce9626e855f6.
    [cone.scad, cone.stl, cone_profile.csv]
2026-01-02 Revert "partially did tofs"
    This reverts commit 7cc45da3019f5272dff102d14f68ce9626e855f6.
    [OSHW-Logo-R2000.dxf, XM125_Breakout.brd, XM125_Breakout.kicad_pcb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]
2026-01-02 re buploaded tofs + kinda renamed and commited plagiarism
    [XM125_Breakout.brd, XM125_Breakout.kicad_pcb, XM125_Breakout.kicad_sch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]
2026-01-03 made schematics more organised ish for tofs
    Hope i didnt mess anyuthingn up
    [XM125_Breakout.kicad_pcb, XM125_Breakout.kicad_sch]
2026-01-05 got l2 out of l2
    [layer2.kicad_pcb, layer2.kicad_sch]
2026-01-05 veryuseless change added dxf
    [layer1.kicad_pcb]
2026-01-05 added light ring schematics
    [layer1.kicad_pcb, layer1.kicad_sch]
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2026-01-06 feat: layer1 light ring
    [layer1.kicad_pcb]
2026-01-06 chore: stupid light ring more
    [layer1.kicad_pcb, layer1.kicad_sch]
2026-01-07 did l1 light ring partially
    [layer1.kicad_pcb, layer1.kicad_sch]
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2026-01-07 added connectors for modules in schmatics
    [layer1.kicad_pcb, layer1.kicad_sch]
2026-01-07 mostly done with l1 scchematics
    [layer1.kicad_sch]
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2026-01-08 chore: wheels 3mf files
    [inner-layer.3mf, middle-layer.3mf, outer-layer.3mf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]
2026-01-08 chore: kicker 3mf files
    [kicker-all-parts.3mf, kicker-plate.3mf, solenoid-cover.3mf]
2026-01-08 chore: dribbler 3mf files
    [dribbler-drum-rollers-attachment.3mf, dribbler-mount-left.3mf, dribbler-mount-right.3mf]
2026-01-08 fix: dribbler 3mf files
    [dribbler-all-parts.3mf]
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2026-01-08 feat: battery mount parts
    [battery-case-cover.3mf, battery-case.3mf, battery-mount-all-parts.3mf]
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2026-01-08 fix: wheels cad
    [inner-layer.3mf, middle-layer.3mf, outer-layer.3mf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]
2026-01-08 fix: layer1 pcb
    [layer1.kicad_pcb, layer1.kicad_sch]
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2026-01-09 feat: layer2 motor driver footprint and schematic
    [layer2.kicad_pcb, layer2.kicad_sch]
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2026-01-10 l1: added some stuff havent connected data to drivers yet
    [layer1.kicad_pcb, layer1.kicad_sch]
2026-01-10 connectred the pins for driver
    [layer1.kicad_pcb, layer1.kicad_sch]
2026-01-13 added lightgate kicad file
    [Lightgate(LED).kicad_pcb, Lightgate(LED).kicad_sch, lightgate-ldr-pcb-v1.0.dxf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]
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2026-01-14 fixed light gate jst
    [Lightgate(LDR).kicad_pcb, Lightgate(LDR).kicad_sch, Lightgate(LED).kicad_pcb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]
2026-01-14 did some stuff on l2
    [layer2.kicad_pcb, layer2.kicad_sch]
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2026-01-15 did smnth to l2
    [layer2.kicad_pcb, layer2.kicad_sch]
2026-01-15 FInished L2-l3 connection and branding
    [layer2.kicad_pcb, layer2.kicad_sch]
2026-01-17 tofs:debranded it and added 1 via to add gnd fill
    [XM125_Breakout.kicad_pcb]
2026-01-17 did a bit of buck
    [buck.kicad_pcb, buck.kicad_sch]
2026-01-17 buck seems done idk
    [buck.kicad_pcb]
2026-01-17 driver jsts r almost done ig
    [layer1.kicad_pcb, layer1.kicad_sch]
2026-01-17 Revert "driver jsts r almost done ig"
    This reverts commit 0dd8e7197cd13faec0b768cbe0f6c1db0f8b679d.
    [layer1.kicad_pcb, layer1.kicad_sch]
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2026-01-18 l1 half motors done
    [layer1.kicad_pcb, layer1.kicad_sch, layer2.kicad_pcb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]
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2026-01-19 touched lit 1 thing on l2
    [layer2.kicad_pcb]
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2026-01-19 Revert "b bmm mm"
    This reverts commit d7770a863270f1cb970ce90ee83eb730e8b22a2d.
    [buck.kicad_pcb]
2026-01-19 Revert "wdicajdfkj,"
    This reverts commit 449301836dc9eb174cafc9138a1f848e041cf83e.
    [buck.kicad_pcb]
2026-01-19 Revert "wdicajdfkj,"
    This reverts commit db7a6f9b2f59baf1fef59c53f0e0732f06b8b58b.
    [buck.kicad_pcb]
2026-01-19 Revert "wdicajdfkj,"
    This reverts commit e49fd520bb1bff58c9ec61a88596577cb6380b2a.
    [buck.kicad_pcb, buck.kicad_sch, layer2.kicad_pcb]
2026-01-19 Revert "buck seems done idk"
    This reverts commit 98c0c33bcc0f6ab69bf7f0e82d9e932e885d420a.
    [buck.kicad_pcb]
2026-01-19 Revert "did a bit of buck"
    This reverts commit f549f5fa1dabaa1ceabc4869307f1601dc61308a.
    [buck.kicad_pcb, buck.kicad_sch]
2026-01-19 unfucked bucks and touched on l1/2
    [buck.kicad_pcb, buck.kicad_sch, layer1.kicad_pcb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]
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2026-01-24 feat: cone mech files
    [cone.step]
2026-01-24 prod: l1 pcba prod
    [layer1.kicad_pcb]
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2026-01-24 did pcba for tofs+increased dist between l1 to3 connection and sol activationi
    [BOM-XM125_Breakout.csv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]
2026-01-25 l2 : moved a singular via
    [layer2.kicad_pcb]
2026-01-26 fix: minor issues
    [layer1.kicad_pcb, layer2.kicad_pcb]
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2026-01-28 fix: restart
    [AON6354.STEP, BOM-Lightgate(LDR).csv, BOM-Lightgate(LED).csv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]
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2026-01-29 chore: l1 mux routing
    [layer1.kicad_pcb, layer1.kicad_sch]
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2026-01-29 docs: remark on phototransistors and photodiodes
    [layer1.kicad_sch]
2026-01-29 fix: l1 gnd
    [BOM-elec.csv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]
2026-01-29 fix: l1; chore: l2 schematics
    [layer1.kicad_pcb, layer2.kicad_sch]
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2026-02-03 fix: l2
    [BOM-layer2.csv, layer1.kicad_pcb, layer1.step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]
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2026-02-06 fix: l3
    [layer2.step, layer3.kicad_pcb, layer3.step]
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2026-02-11 l3: changed gpio pins for esp32 to avoid 2 and 9
    [layer3.kicad_pcb, layer3.kicad_sch]
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2026-02-18 fix: mech: ir shell
    [IR_Shell.3mf]
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2026-02-20 changed chenxuan mistake on l1
    [layer1.kicad_pcb, layer1.kicad_sch]
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2026-02-27 fix: l1; prod: l1
    [BOM-layer1.csv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]
2026-02-27 fix: l1
    [layer1.kicad_pcb, layer1.kicad_sch]
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2026-02-28 fixed enable pull dowj
    [BOM-layer2.csv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]
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2026-03-01 all layes drc and fixed
    [layer1.kicad_pcb, layer2.kicad_pcb, layer3.kicad_pcb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]
2026-03-02 chore: fix all 3 layers; prod: all 3 layers
    [BOM-layer1.csv, BOM-layer2.csv, BOM-layer3.csv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]
2026-03-03 fix: fix code to take average instead
    [main.cpp]
2026-03-10 chore: mech: fix top layers
    [camera-mount.dxf, layer4-pcb.dxf]
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2026-03-12 feat: l2 init code, fix
    [main.cpp]
2026-03-12 fix: l2 init code
    [main.cpp]
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2026-03-16 feat: mech: dribbler fixes, kicker fixes
    [42mm-standoff.3mf, dribbler-mount-left.3mf, dribbler-mount-right.3mf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]
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2026-03-20 chore: mech: fix dribbler
    [dribbler-drum-rollers-attachment.3mf]
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2026-03-20 feat: major movement code fixes and improvements
    [config.h, main.cpp]
2026-03-20 chore: movement tuning and algorithom fixes
    [config.h]
2026-03-21 chore: fix ir code to use num of ir not num of counts
    [main.cpp]
2026-03-21 chore: fix ir detection, change ir calculation
    [main.cpp]
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2026-03-27 fix: fix moveRobot code, program move to ball
    [main.cpp]
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2026-04-10 chore: idk line avoidance or somethig
    [config.h, main.cpp]
2026-05-06 Correct camera documentation
